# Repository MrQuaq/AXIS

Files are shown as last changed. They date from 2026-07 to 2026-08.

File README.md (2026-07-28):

# **AXIS — Balancing robot**

***AXIS is a dual wheeled self-balancing robot built around an ESP32 and custom PCB!***

### **Project overview**

AXIS is a dual wheeled balancing robot, using a PID algorithm to keep its balance. The main microcontroller of the robot will be the ESP32. This enables the use of an Xbox controller for controlling the robot. Certain buttons on the controller will be mapped to the pid value settings so they can be changed on the fly, which should make the tuning process a lot easier.

As an additional feature that will be tested after the robot is already stable, 2 encoders that are already mounted on the motors will be added. Their data will be used in a second PID algorithm to hopefully get the robot to stay in a single place a lot easier. This feature is still completely optional and can easily be turned on by a button on the Xbox controller.

### **Goals**

The goal of this project is to become more familiarized with electronics to get a good foundation for future projects. And to grasp the basics of PCB-design.

The goal for the robot itself is to make it balance without jittering too much and to make it drivable via a controller.

### **Key components**

- Custom PCB to mount breakout boards on  
- 3D-printed frame  
- Custom code featuring a PID algorithm and bluetooth connection

### **PCB design**

This PCB features lots of female header pins to mount existing breakout boards onto. This framework makes for more reliable connections and pcb-design experience.  
To design the board I used KiCAD, a free open-source EDA.

The first step in the design process was coming up with the requirements and features of the board.  
These include:

- Measuring the robots angle reliably  
- Driving the motors  
- Being able to connect a small lcd display for easier status updates and eventually PID tuning  
- Accept power from a 7,2V NiMH battery  
- Have connectors for encoders

After setting these requirements, a schematic was designed before moving on to the actual tracing. This also enabled me to become even more familiarized with the design and the components.

With the schematic made, the pcb tracing was fairly easy. I paid special attention to the spacing between the female pin headers so the modules would fit properly. A ground plane was also added on the bottom of the PCB to make wiring easier. To disturb this plane as little as possible, I tried to lay out the PCB in such a way that I have almost no traces on the back side.  
The final PCB features:

- Headers for ESP32  
- Headers for IMU module (ICM20948)  
- Headers for motor driver (tb6612fng)  
- Headers for lcd display  
- Screw terminals for motors and encoders  
- Components to provide the right (and stable) voltages to all components  
- Protection components

### **3D-CAD**

For the CAD I used a program I’m fairly familiar with; Fusion 360.  
The frame is divided into 3 key parts:

- Motor mount  
- Bottom compartment  
- Top compartment

The motor mount is made so that the motor has no room to shake. This results in a weird internal shape because of the irregular shape of the motor with right angle gearbox. Additionally the motor is able to be secured with 4 screws via the motor mount cover. This cover also features some cooling slots (but I doubt I need them).

Further up, we have the bottom compartment of the head. This houses the custom PCB. Connections to the encoders and motors pass through the bottom to the motor mount.

Above, there is the top compartment of the head. Here is the battery, LCD screen and switch. Again, their connections will pass through the bottom to the compartment below.  
Finally a lid, secured with magnets for easy access, covers up the top.

### **Timeline**

What’s already been done:

- Full code (imu, controller, PID’s and motor)  
- PCB design in KiCad  
- IMU testing  
- Motor testing  
- PID testing (imu and motor)  
- 3D-CAD

What still needs to be done:

- 3D printing the frame  
- Ordering the PCB  
- Final assembly  
- PID tuning

### **Gallery**

##### 3D-CAD

| | |
| :---: | :---: |
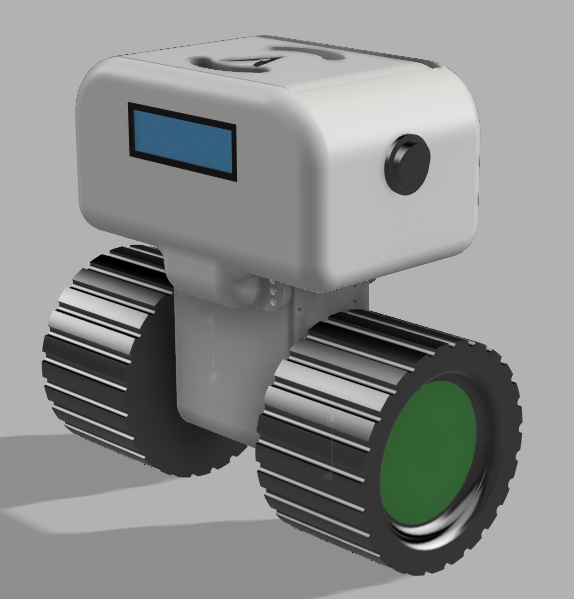
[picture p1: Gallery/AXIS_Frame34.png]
AXIS Frame 34
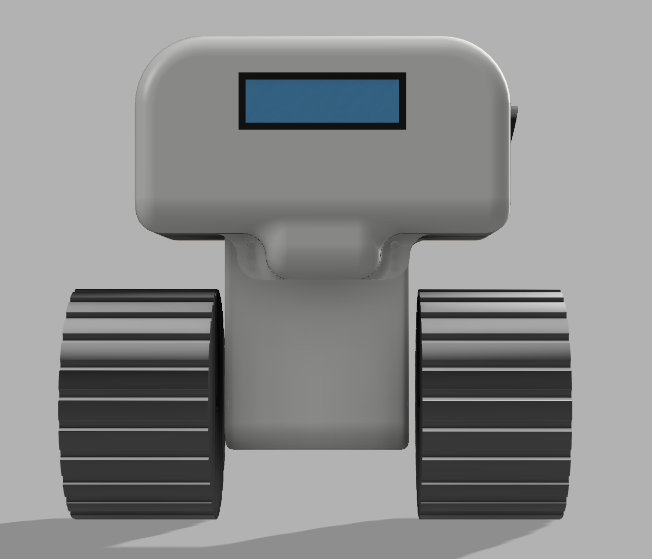
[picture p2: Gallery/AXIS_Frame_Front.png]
AXIS Frame Front
|  |  |
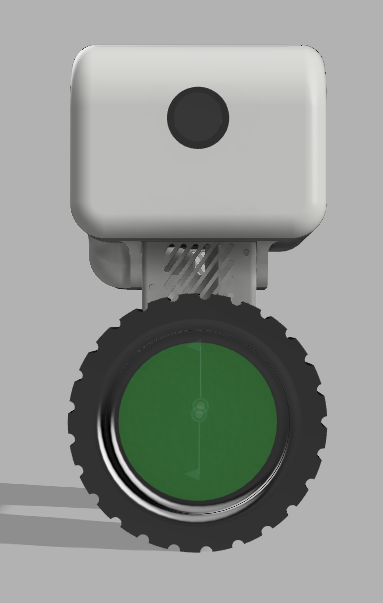
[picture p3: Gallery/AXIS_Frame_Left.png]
AXIS Frame Left
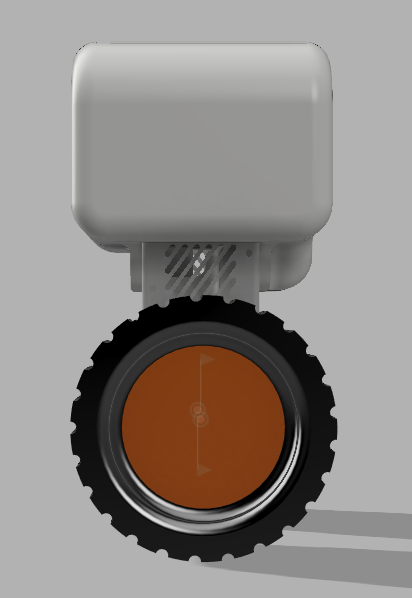
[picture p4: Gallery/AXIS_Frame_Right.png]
AXIS Frame Right
|  |  |
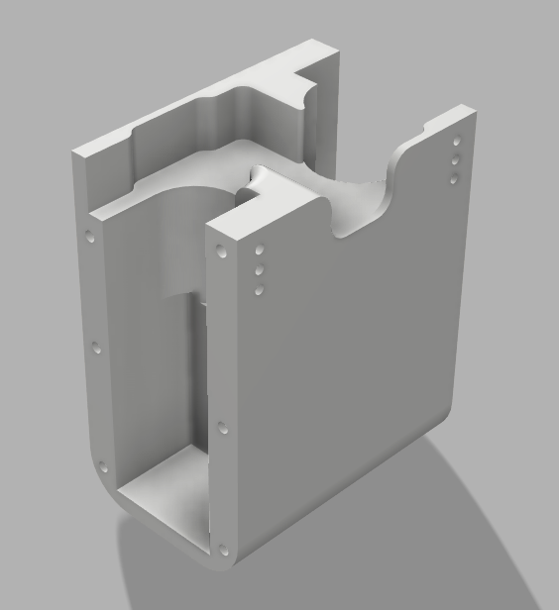
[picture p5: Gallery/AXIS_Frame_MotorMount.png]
AXIS Frame Motor Mount
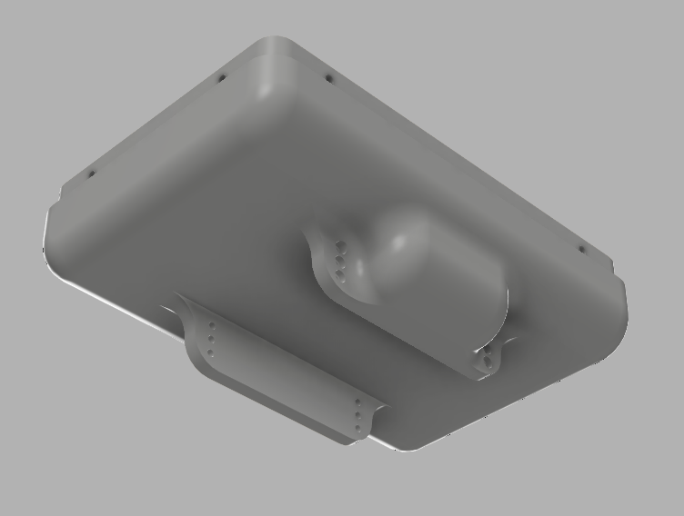
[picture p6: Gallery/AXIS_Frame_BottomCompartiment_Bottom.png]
AXIS Frame Bottom Compartiment Bottom
|  |  |
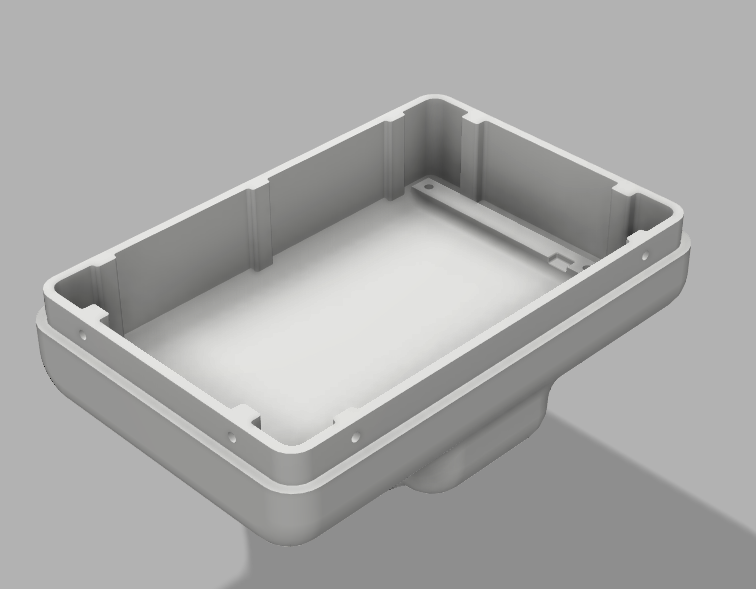
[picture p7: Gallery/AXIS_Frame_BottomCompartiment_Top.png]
AXIS Frame Bottom Compartiment Top
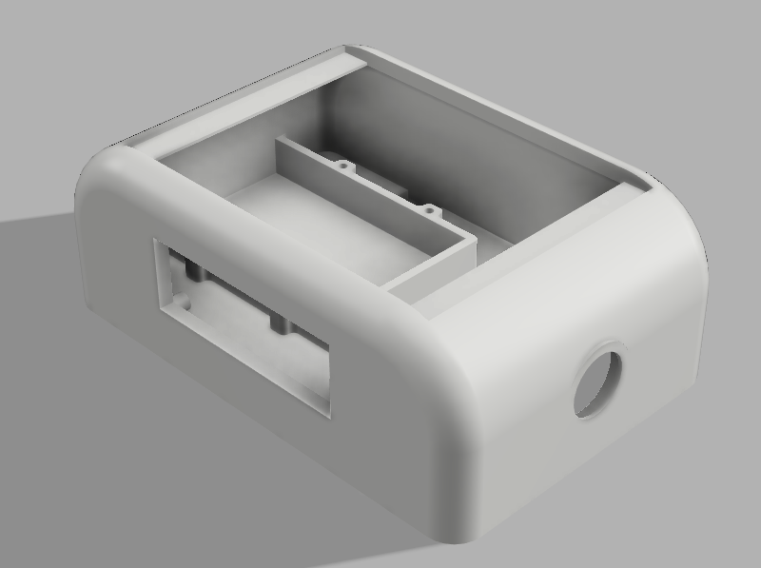
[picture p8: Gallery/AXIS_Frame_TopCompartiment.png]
AXIS Frame Top Compartiment
|  |  |

##### PCB-design

| | |
| :---: | :---: |
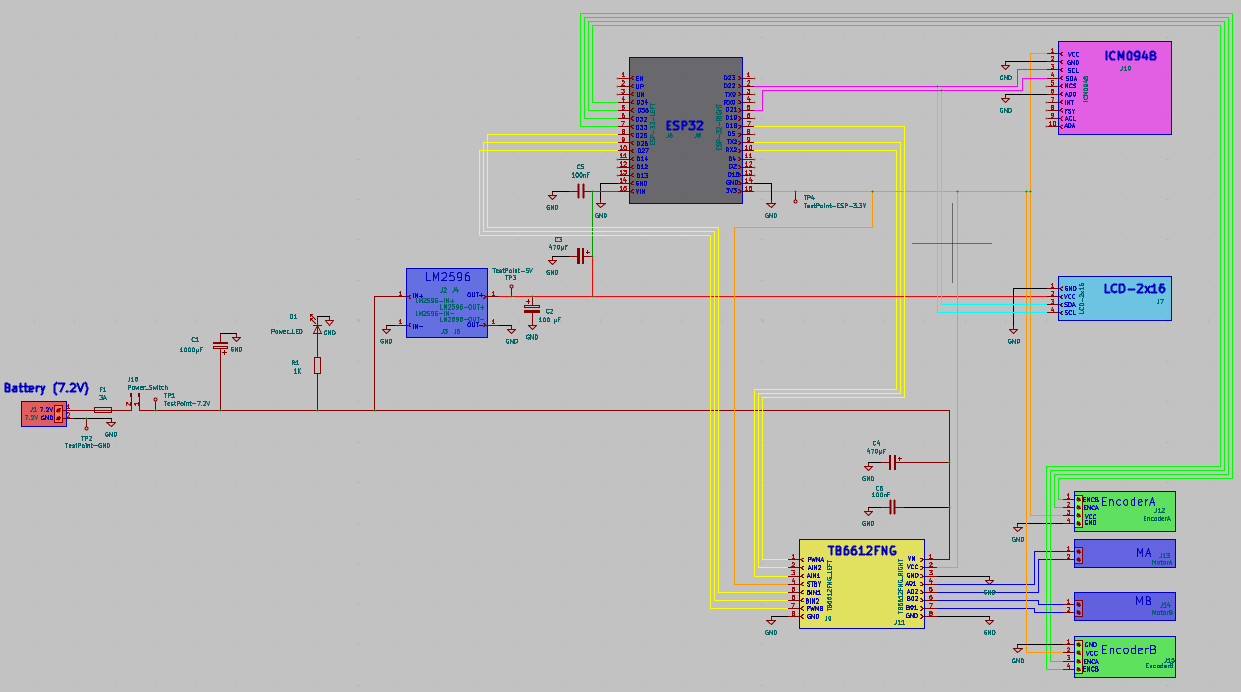
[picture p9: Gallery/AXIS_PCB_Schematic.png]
AXIS PCB Schematic
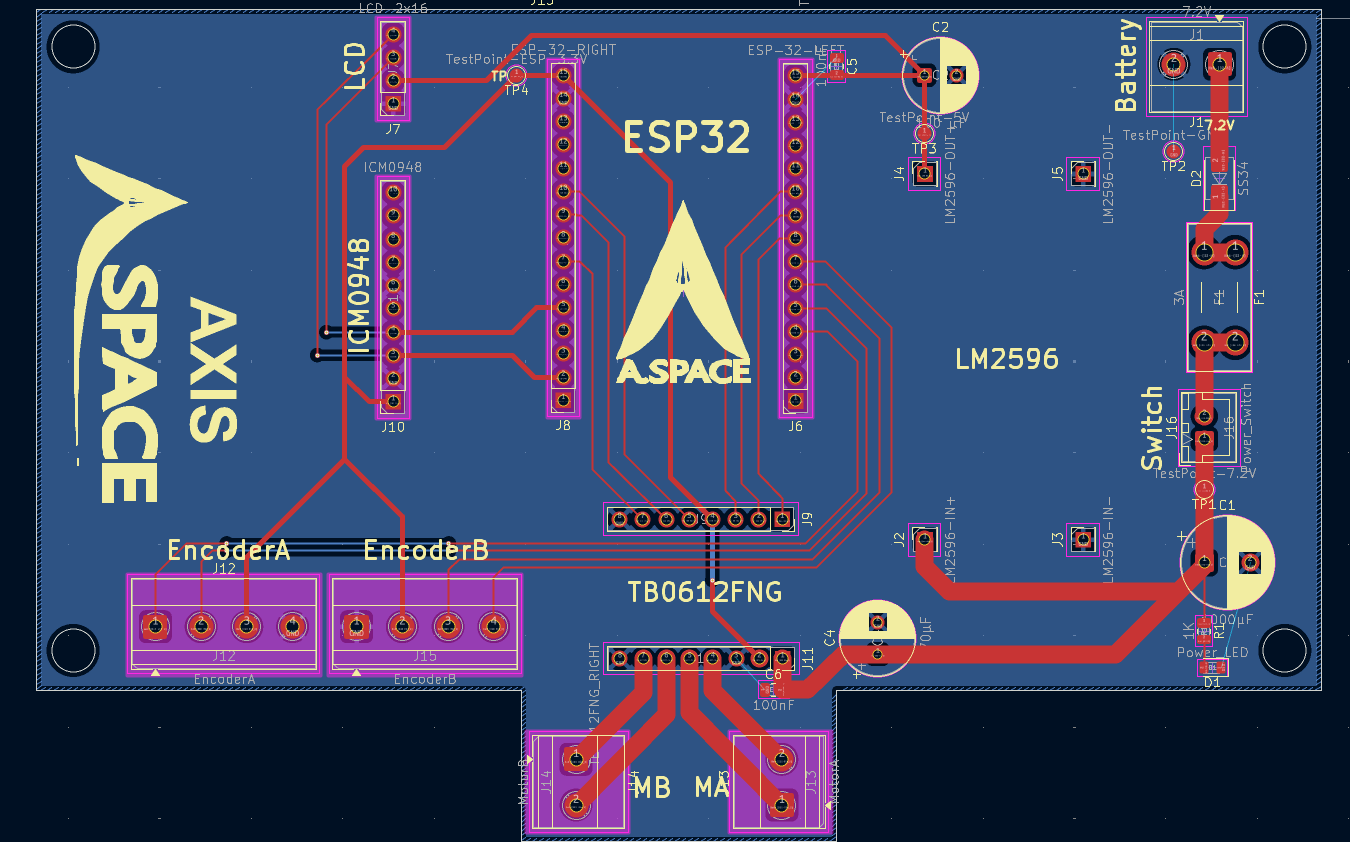
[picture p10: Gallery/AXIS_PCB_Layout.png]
AXIS PCB Layout
|  |  |
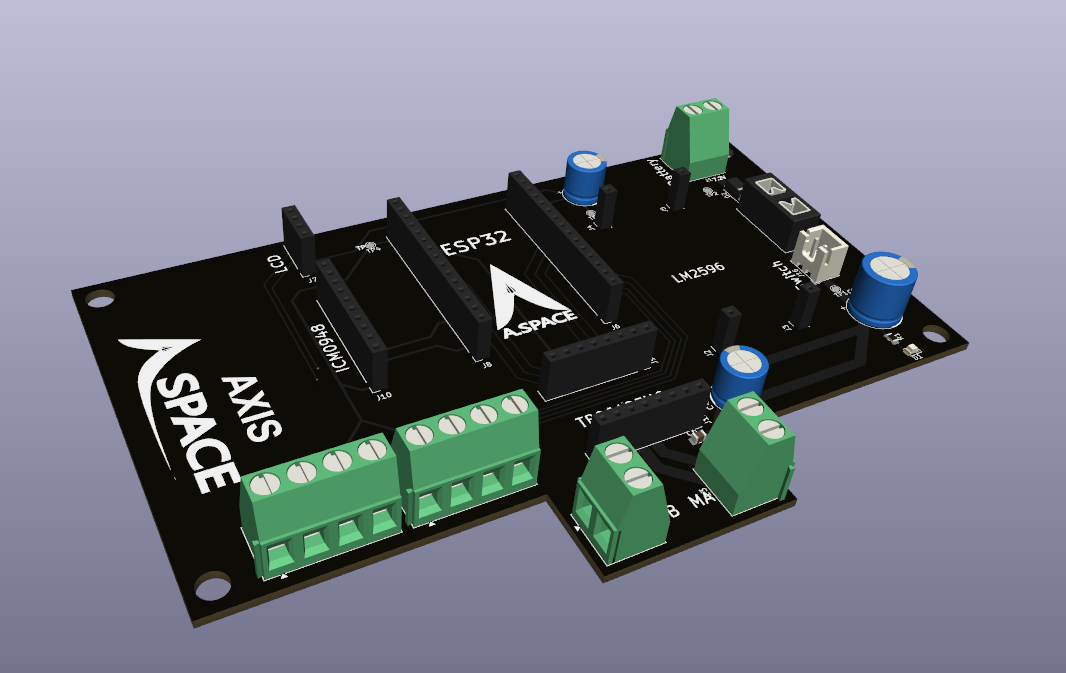
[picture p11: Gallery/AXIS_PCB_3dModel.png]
AXIS PCB 3dModel
|  | |

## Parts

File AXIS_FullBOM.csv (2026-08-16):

Part | Quantity | In possesion
ESP-32 module | 1 | TRUE
TB6612FNG module | 1 | TRUE
LM2596 module | 1 | TRUE
DC motor with encoder | 2 | TRUE
16 char LCD display | 1 | TRUE
7,2V Ni Mah battery | 1 | TRUE
switch | 1 | TRUE
Part | Quantity | In possesion
1kg PLA filament | 1 | TRUE
Wheel | 2 | TRUE
Index | Manufacturer Part Number | Manufacturer Name | Description | Attrition % | Requested Quantity 1 | Pack Quantity 1 | Pack Type 1 | Digi-Key Part Number 1 | Unit Price 1 | Extended Price 1 | Minimum Order Quantity 1 | Requested Part Number | Reference Designator | Original Part numbers | Unit of Measure | Product Notes
1 | SS34 | Shenzhen Slkormicro Semicon Co., Ltd. | DIODE SCHOTTKY 40V 3A DO214AC |  | 2 | 2 | Cut Tape (CT) | 5399-SS34CT-ND | 0,13000 | €0.26 | 1 | 5399-SS34CT-ND |  | 5399-SS34CT-ND | Each
2 | 3568 | Keystone Electronics | FUSE HOLDER BLADE 500V 30A PCB |  | 2 | 2 | Bulk | 36-3568-ND | 1,18000 | €2.36 | 1 | 36-3568-ND |  | 36-3568-ND | Each
3 | 1729128 | Phoenix Contact | TERM BLK 2P SIDE ENT 5.08MM PCB |  | 6 | 6 | Bulk | 277-1247-ND | 0,83000 | €4.98 | 1 | 277-1247-ND |  | 277-1247-ND | Each
4 | 1729144 | Phoenix Contact | TERM BLK 4P SIDE ENT 5.08MM PCB |  | 4 | 4 | Bulk | 277-1249-ND | 1,70000 | €6.80 | 1 | 277-1249-ND |  | 277-1249-ND | Each
5 | SSW-101-02-G-S | Samtec Inc. | CONN RCPT .100" 1POS SNGL GOLD |  | 8 | 8 | Bulk | 612-SSW-101-02-G-S-ND | 0,66000 | €5.28 | 1 | 612-SSW-101-02-G-S-ND |  | 612-SSW-101-02-G-S-ND | Each
6 | SSW-115-02-G-S | Samtec Inc. | CONN RCPT .100" 15POS SNGL GOLD |  | 4 | 4 | Bulk | 612-SSW-115-02-G-S-ND | 2,83000 | €11.32 | 1 | 612-SSW-115-02-G-S-ND |  | 612-SSW-115-02-G-S-ND | Each
7 | SSW-104-02-G-S | Samtec Inc. | CONN RCPT .100" 4POS SNGL GOLD |  | 2 | 2 | Bulk | 612-SSW-104-02-G-S-ND | 1,22000 | €2.44 | 1 | 612-SSW-104-02-G-S-ND |  | 612-SSW-104-02-G-S-ND | Each
8 | SSW-110-02-G-S | Samtec Inc. | CONN RCPT .100" 10POS SNGL GOLD |  | 2 | 2 | Bulk | 612-SSW-110-02-G-S-ND | 1,89000 | €3.78 | 1 | 612-SSW-110-02-G-S-ND |  | 612-SSW-110-02-G-S-ND | Each
9 | SSW-108-02-G-S | Samtec Inc. | CONN RCPT .100" 8POS SNGL GOLD |  | 4 | 4 | Bulk | 612-SSW-108-02-G-S-ND | 1,51000 | €6.04 | 1 | 612-SSW-108-02-G-S-ND |  | 612-SSW-108-02-G-S-ND | Each
10 | B2B-XH-A | JST Sales America Inc. | CONN HEADER VERT 2POS 2.5MM |  | 2 | 2 | Bulk | 455-B2B-XH-A-ND | 0,09000 | €0.18 | 1 | 455-B2B-XH-A-ND |  | 455-B2B-XH-A-ND | Each
11 | RC0805FR-131KL | YAGEO | RES 1K OHM 1% 1/8W 0805 |  | 2 | 2 | Cut Tape (CT) | 13-RC0805FR-131KLCT-ND | 0,09000 | €0.18 | 1 | 13-RC0805FR-131KLCT-ND |  | 13-RC0805FR-131KLCT-ND | Each
12 | 16SEPF1000M | Panasonic Industry | CAP ALUM POLY 1000UF 20% 16V TH |  | 2 | 2 | Bulk | P16300-ND | 2,21000 | €4.42 | 1 | P16300-ND |  | P16300-ND | Each
13 | 16SEPG470M | Panasonic Industry | CAP ALUM POLY 470UF 20% 16V TH |  | 2 | 2 | Bulk | P122605-ND | 1,52000 | €3.04 | 1 | P122605-ND |  | P122605-ND | Each
14 | C0805J104K3RACTU | KEMET | .100UF 25.0V |  | 4 | 4 | Cut Tape (CT) | 399-C0805J104K3RACTUCT-ND | 0,67000 | €2.68 | 1 | 399-C0805J104K3RACTUCT-ND |  | 399-C0805J104K3RACTUCT-ND | Each
15 | LG R971-KN-1-0-20-R18 | ams OSRAM AG | LED GREEN DIFFUSED 0805 SMD |  | 2 | 2 | Cut Tape (CT) | 475-LGR971-KN-1CT-ND | 0,15000 | €0.30 | 1 | 475-LGR971-KN-1CT-ND |  | 475-LGR971-KN-1CT-ND | Each
16 | 35RX30100M8X11.5 | Rubycon | CAP ALUM 100UF 20% 35V RADIAL TH |  | 2 | 2 | Bulk | 1189-1895-ND | 0,47000 | €0.94 | 1 | 1189-1895-ND |  | 1189-1895-ND | Each
 | PCB | PCB Parts | Total needed
 | €35.52 | €55,00 | €90,52

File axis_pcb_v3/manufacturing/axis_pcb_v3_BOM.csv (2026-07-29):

Comment | Designator | Footprint | Quantity
Power_LED | D1 | LED_0805_2012Metric | 1
LM2596-OUT+ | J4 | PinSocket_1x01_P2.54mm_Vertical | 1
100nF | C5,C6 | C_0805_2012Metric | 2
TestPoint-GND | TP2 | TestPoint_Pad_D1.5mm | 1
ESP-32-LEFT | J6 | PinSocket_1x15_P2.54mm_Vertical | 1
MotorB | J14 | TerminalBlock_Phoenix_MKDS-1,5-2_1x02_P5.00mm_Horizontal | 1
TestPoint-ESP-3.3V | TP4 | TestPoint_Pad_D1.5mm | 1
MotorA | J13 | TerminalBlock_Phoenix_MKDS-1,5-2_1x02_P5.00mm_Horizontal | 1
EncoderB | J15 | TerminalBlock_Phoenix_MKDS-1,5-4_1x04_P5.00mm_Horizontal | 1
TestPoint-7.2V | TP1 | TestPoint_Pad_D1.5mm | 1
1000µF | C1 | CP_Radial_D10.0mm_P5.00mm | 1
7.2V | J1 | TerminalBlock_Phoenix_MKDS-1,5-2_1x02_P5.00mm_Horizontal | 1
SS34 | D2 | D_SMA | 1
ICM0948 | J10 | PinSocket_1x10_P2.54mm_Vertical | 1
470µF | C4 | CP_Radial_D8.0mm_P3.50mm | 1
TB6612FNG_LEFT | J9 | PinSocket_1x08_P2.54mm_Vertical | 1
LM2596-IN- | J3 | PinSocket_1x01_P2.54mm_Vertical | 1
ESP-32-RIGHT | J8 | PinSocket_1x15_P2.54mm_Vertical | 1
TB6612FNG_RIGHT | J11 | PinSocket_1x08_P2.54mm_Vertical | 1
LCD-2x16 | J7 | PinSocket_1x04_P2.54mm_Vertical | 1
LM2596-OUT- | J5 | PinSocket_1x01_P2.54mm_Vertical | 1
Power_Switch | J16 | JST_XH_B2B-XH-A_1x02_P2.50mm_Vertical | 1
3A | F1 | Fuseholder_Blade_Mini_Keystone_3568 | 1
LM2596-IN+ | J2 | PinSocket_1x01_P2.54mm_Vertical | 1
100 µF | C2 | CP_Radial_D8.0mm_P3.50mm | 1
TestPoint-5V | TP3 | TestPoint_Pad_D1.5mm | 1
1K | R1 | R_0805_2012Metric | 1
EncoderA | J12 | TerminalBlock_Phoenix_MKDS-1,5-4_1x04_P5.00mm_Horizontal | 1

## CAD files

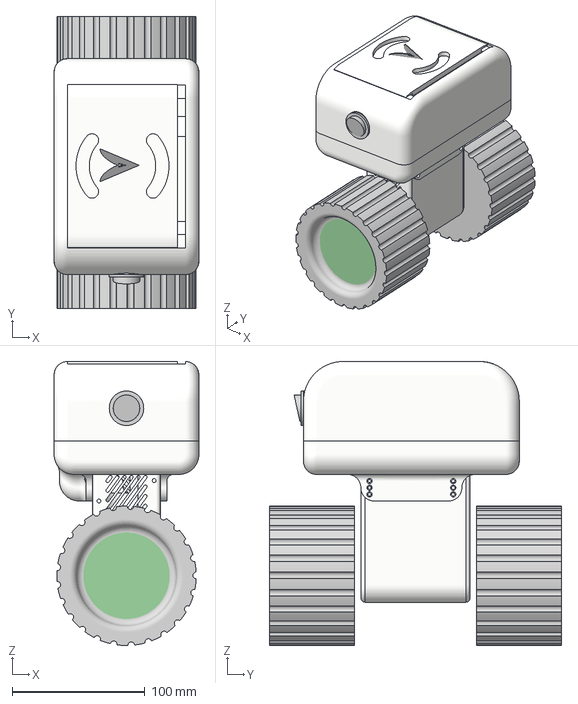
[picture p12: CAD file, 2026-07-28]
AXIS_Frame/AXIS_Frame_Assembly.3mf
109.0 x 220.0 x 213.7 mm

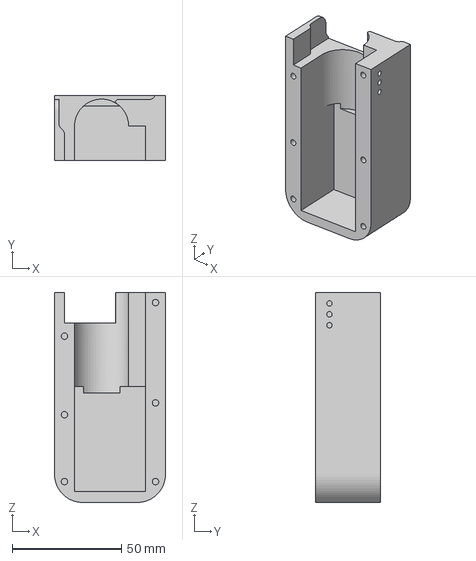
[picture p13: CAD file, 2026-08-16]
AXIS_Frame/MotorMountTest.3mf
50.9 x 30.0 x 96.2 mm

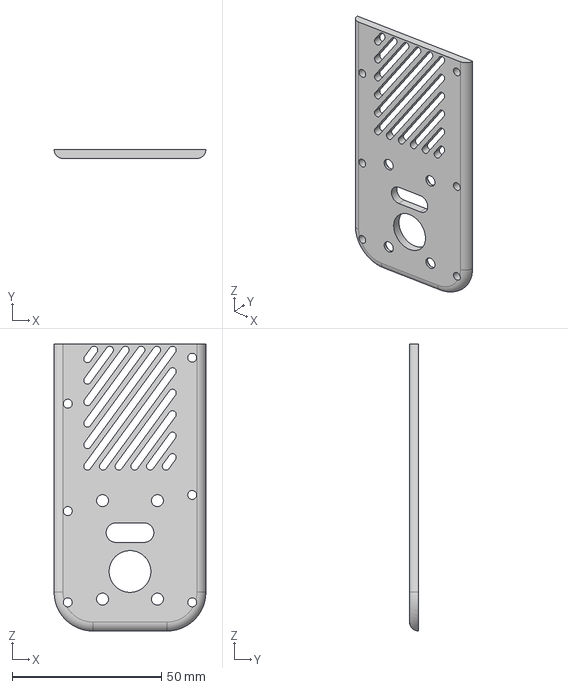
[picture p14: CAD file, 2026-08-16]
AXIS_Frame/MotorCover.step
50.9 x 3.00 x 96.2 mm

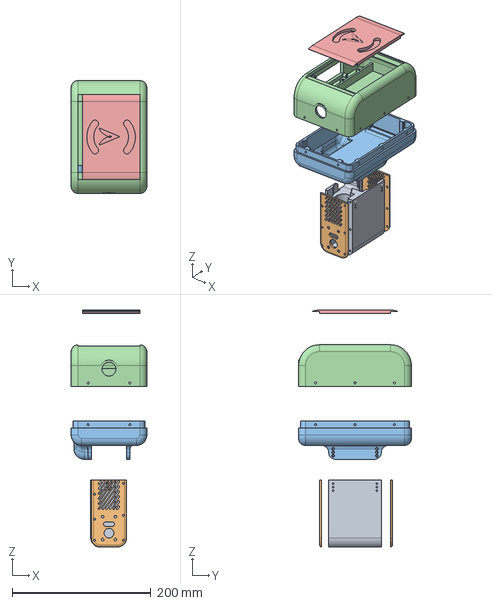
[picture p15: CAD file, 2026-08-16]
AXIS_Frame/AXIS_Frame_DesignFile.step
109.0 x 162.5 x 341.2 mm

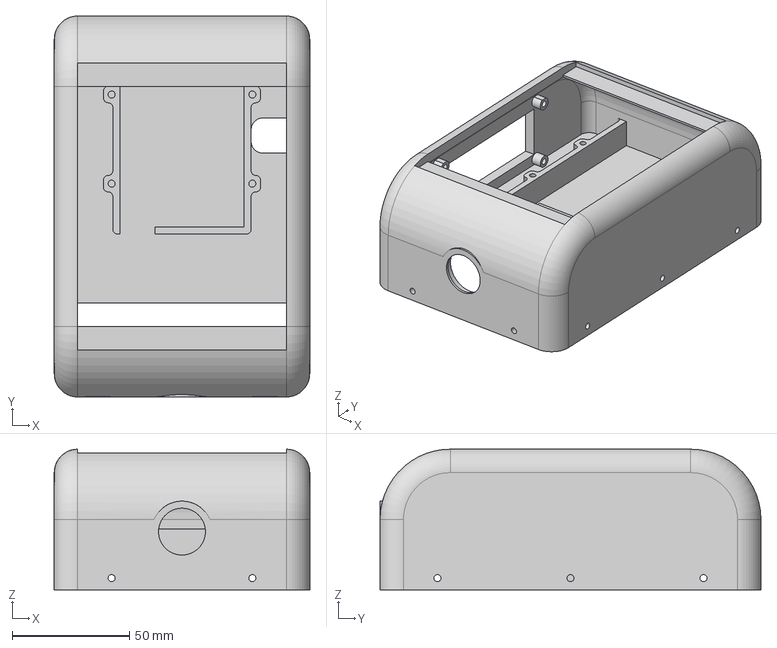
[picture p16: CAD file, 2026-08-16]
AXIS_Frame/TopCompartiment.step
109.0 x 162.5 x 60.0 mm

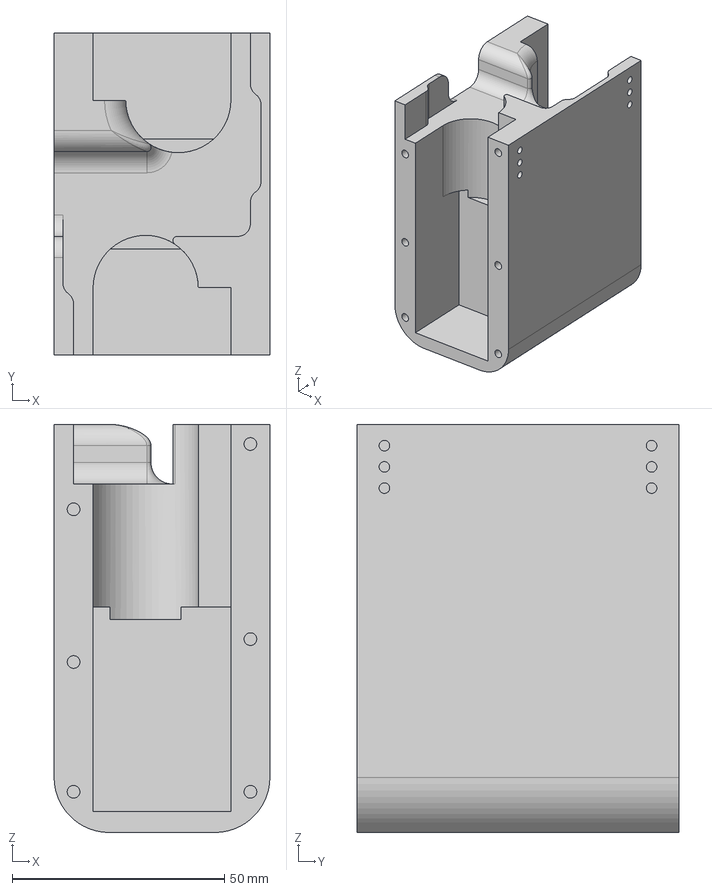
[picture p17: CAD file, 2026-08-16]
AXIS_Frame/MotorMount.step
50.9 x 76.0 x 96.2 mm

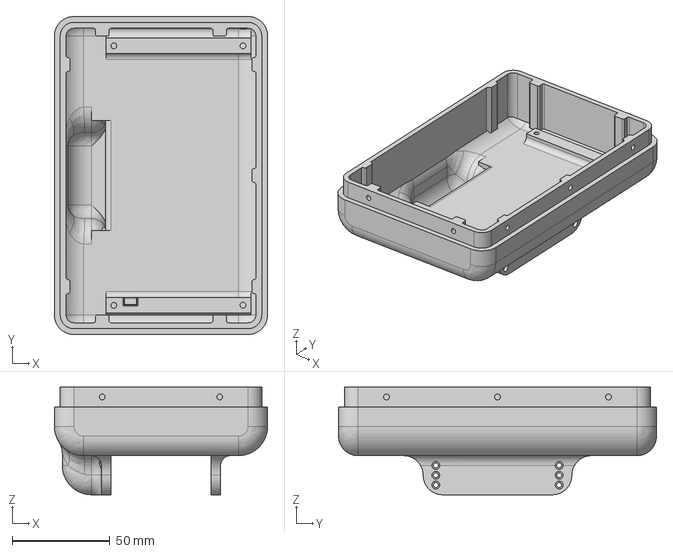
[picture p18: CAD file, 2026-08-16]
AXIS_Frame/BottomCompartiment.step
109.0 x 162.5 x 55.0 mm

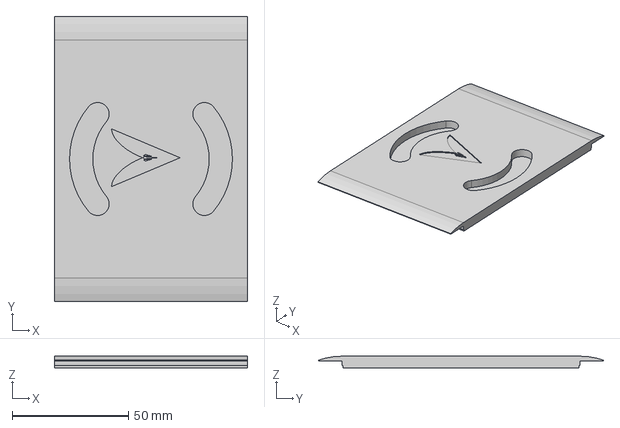
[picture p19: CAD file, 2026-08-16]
AXIS_Frame/TopCover.step
83.0 x 122.5 x 5.00 mm

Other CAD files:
AXIS_Frame/MotorMountCover.3mf
AXIS_Frame/AXIS_MotorMountCover_Test.stl
AXIS_Frame/AXIS_MotorMount_Test.stl
AXIS_Frame/BottomCompartiment.3mf
AXIS_Frame/MotorMount.3mf
AXIS_Frame/TopCompartiment.3mf
AXIS_Frame/TopCover.3mf

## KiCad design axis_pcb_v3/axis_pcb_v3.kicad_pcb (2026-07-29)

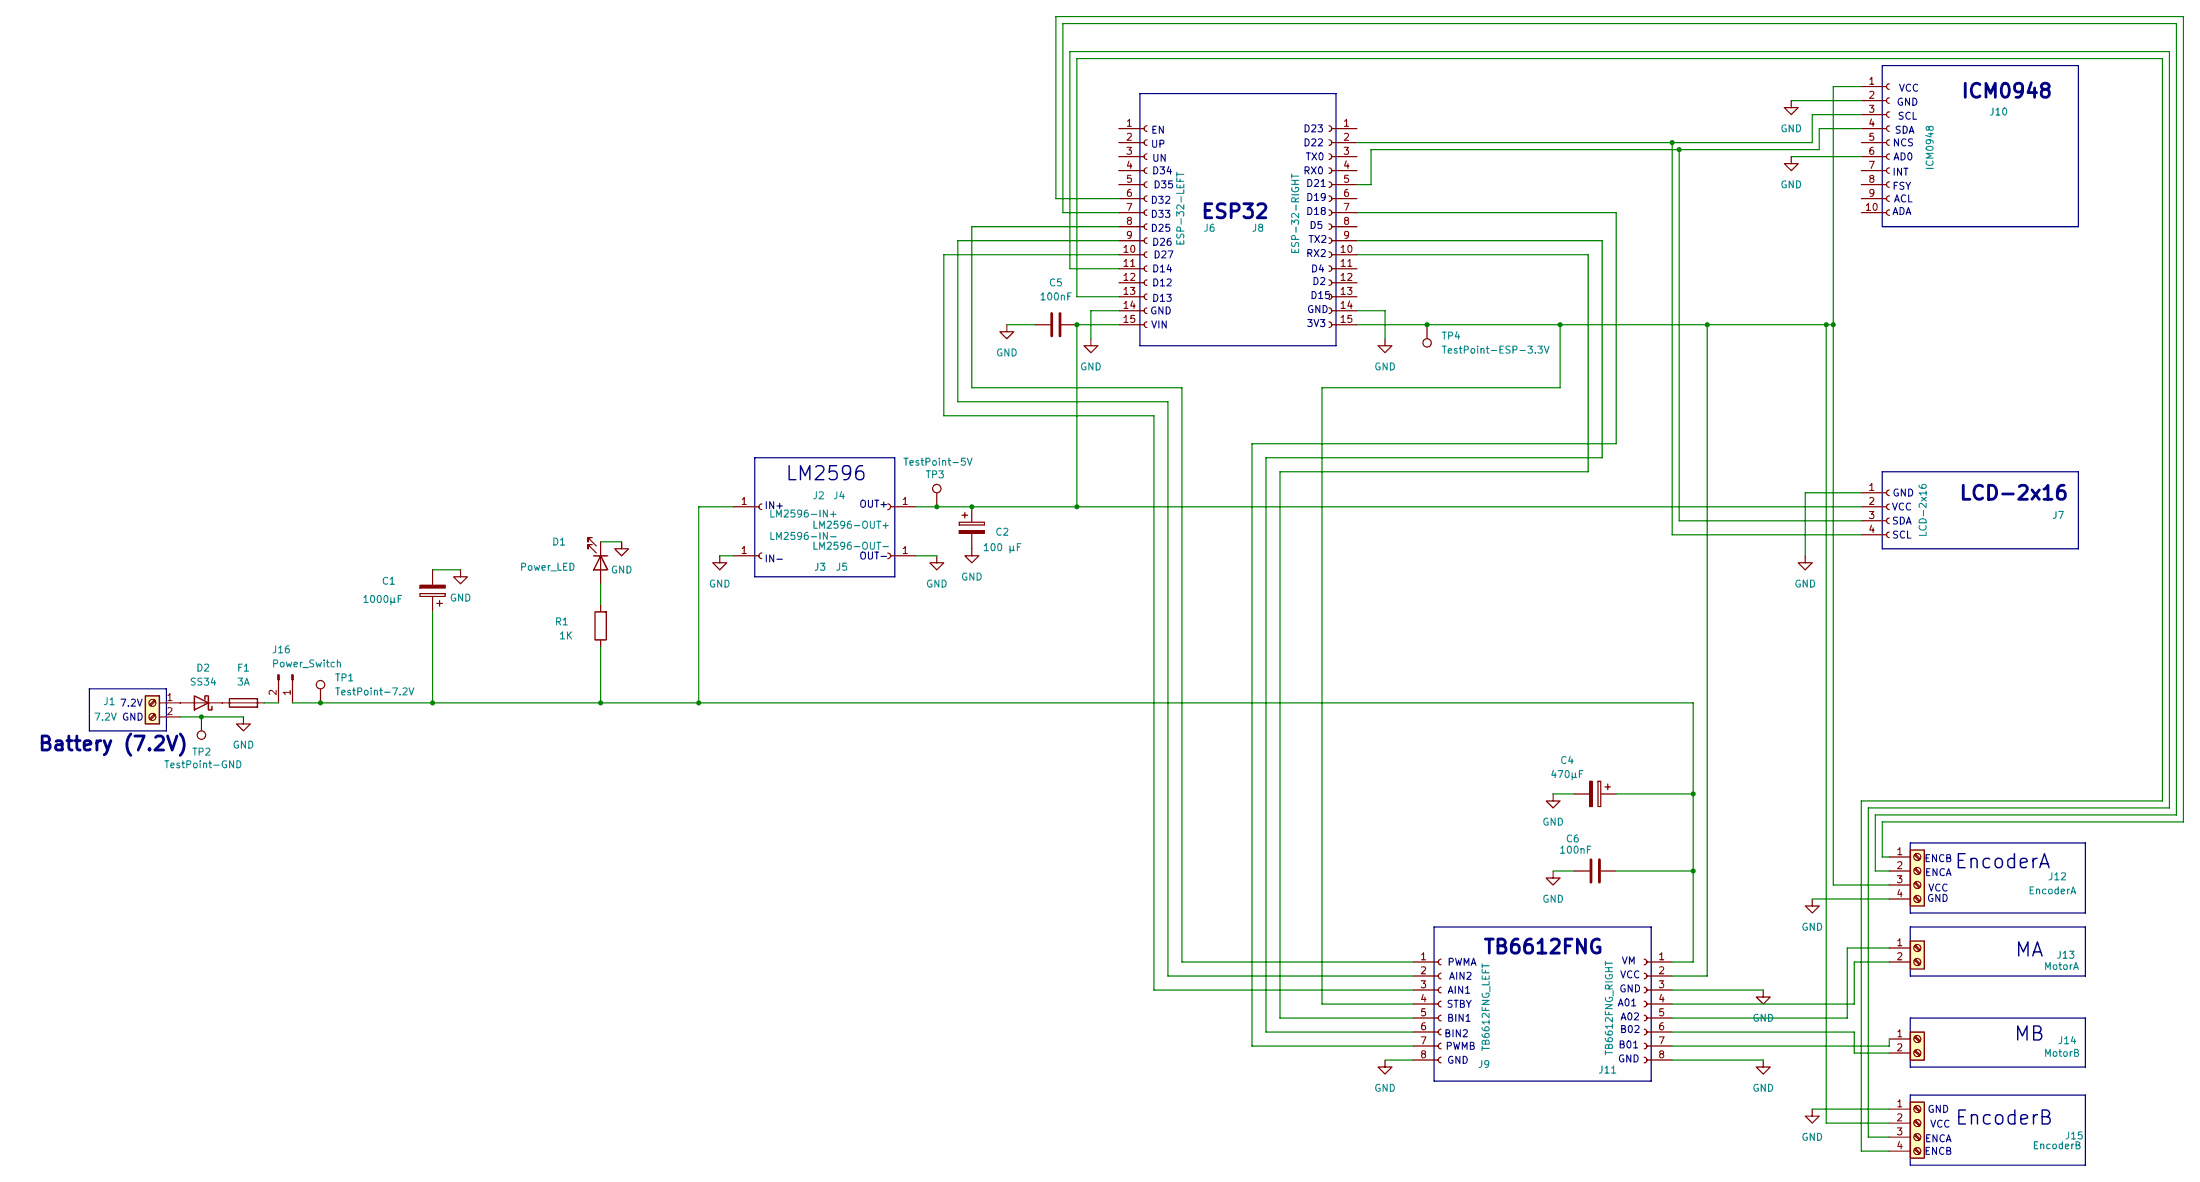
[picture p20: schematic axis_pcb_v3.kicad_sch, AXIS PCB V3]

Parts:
C1: 1000µF; CP_Radial_D10.0mm_P5.00mm
C2: 100 µF; CP_Radial_D8.0mm_P3.50mm
C4: 470µF; CP_Radial_D8.0mm_P3.50mm
C5, C6: 100nF; C_0805_2012Metric
D1: Power_LED; LED_0805_2012Metric
D2: SS34; D_SMA
F1: 3A; Fuseholder_Blade_Mini_Keystone_3568
J1: 7.2V; TerminalBlock_Phoenix_MKDS-1,5-2_1x02_P5.00mm_Horizontal
J2: LM2596-IN+; PinSocket_1x01_P2.54mm_Vertical
J3: LM2596-IN-; PinSocket_1x01_P2.54mm_Vertical
J4: LM2596-OUT+; PinSocket_1x01_P2.54mm_Vertical
J5: LM2596-OUT-; PinSocket_1x01_P2.54mm_Vertical
J6: ESP-32-LEFT; PinSocket_1x15_P2.54mm_Vertical
J7: LCD-2x16; PinSocket_1x04_P2.54mm_Vertical
J8: ESP-32-RIGHT; PinSocket_1x15_P2.54mm_Vertical
J9: TB6612FNG_LEFT; PinSocket_1x08_P2.54mm_Vertical
J10: ICM0948; PinSocket_1x10_P2.54mm_Vertical
J11: TB6612FNG_RIGHT; PinSocket_1x08_P2.54mm_Vertical
J12: EncoderA; TerminalBlock_Phoenix_MKDS-1,5-4_1x04_P5.00mm_Horizontal
J13: MotorA; TerminalBlock_Phoenix_MKDS-1,5-2_1x02_P5.00mm_Horizontal
J14: MotorB; TerminalBlock_Phoenix_MKDS-1,5-2_1x02_P5.00mm_Horizontal
J15: EncoderB; TerminalBlock_Phoenix_MKDS-1,5-4_1x04_P5.00mm_Horizontal
J16: Power_Switch; JST_XH_B2B-XH-A_1x02_P2.50mm_Vertical
R1: 1K; R_0805_2012Metric
TP1: TestPoint-7.2V; TestPoint_Pad_D1.5mm
TP2: TestPoint-GND; TestPoint_Pad_D1.5mm
TP3: TestPoint-5V; TestPoint_Pad_D1.5mm
TP4: TestPoint-ESP-3.3V; TestPoint_Pad_D1.5mm

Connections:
GND: C1.2, C2.2, C4.2, C5.1, C6.1, D1.1 (K), J1.2, J3.1, J5.1, J6.14, J7.1, J8.14, J9.8, J10.2, J10.6, J11.3, J11.8, J12.4, J15.1, TP2.1
unnamed: D1.2 (A), R1.2
unnamed: D2.2 (A), J1.1
unnamed: D2.1 (K), F1.1
unnamed: C2.1, C5.2, J4.1, J6.15, J7.2, TP3.1
unnamed: J6.8, J9.1
unnamed: J6.9, J9.2
unnamed: J6.10, J9.3
unnamed: J8.7, J9.7
unnamed: J8.9, J9.6
unnamed: J8.10, J9.5
unnamed: J8.15, J9.4, J10.1, J11.2, J12.3, J15.2, TP4.1
unnamed: J7.4, J8.2, J10.3
unnamed: J7.3, J8.5, J10.4
unnamed: C1.1, C4.1, C6.2, J2.1, J11.1, J16.1, R1.1, TP1.1
unnamed: J11.4, J13.2
unnamed: J11.5, J13.1
unnamed: J11.6, J14.2
unnamed: J11.7, J14.1
unnamed: J6.6, J12.1
unnamed: J6.7, J12.2
unnamed: J6.11, J15.3
unnamed: J6.13, J15.4
unnamed: F1.2, J16.2

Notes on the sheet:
EncoderB
PWMA
3V3
D35
D25
D12
ENCA
BIN1
ACL
D26
LM2596
VCC
D34
D13
D21
INT
SCL
VIN
GND
SDA
AIN1
RX0
OUT+
D23
TX0
A02
7.2V
TB6612FNG
B01
D19
TX2
AD0
STBY
OUT-
D22
NCS
EncoderA
ENCB
RX2
ADA

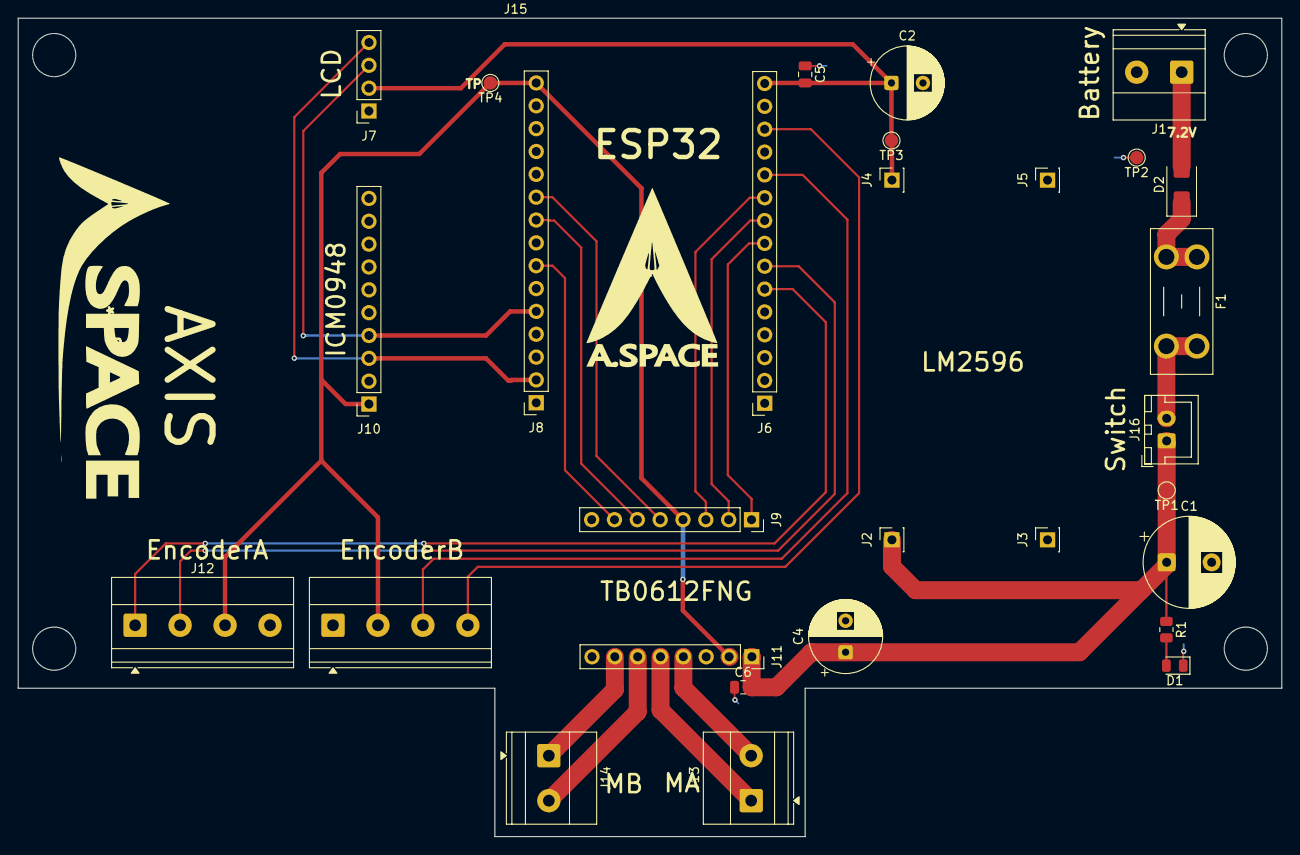
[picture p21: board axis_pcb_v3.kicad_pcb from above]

Board: 2 copper layers, 140.5 x 91.0 mm, 29 parts (0 on the bottom side), 24 nets.

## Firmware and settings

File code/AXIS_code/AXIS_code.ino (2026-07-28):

#include "Globals.h"

double dt = 0.0;
unsigned long last_time;

extern float angle;

double FINALPID_OUTPUT;
double PID_OUTPUT;
double SPEEDPID_OUTPUT;

void setup() {
  setupmotor();
  setupIMU();
  setupcontroller();
  setupEncoders();

  Serial.begin(9600);
}

void loop() {
  //--------DELTA TIME CALCULATION-----------------
  unsigned long now = micros();
  dt = (now - last_time) / 1000000.0;
  last_time = now;

  //-----------FUNCTIONS-----------------
  updateIMU();
  int pwm = controller();
  motor(pwm, FINALPID_OUTPUT);  

  Serial.print(angle);
  Serial.print(",");
  Serial.println(pwm);
}

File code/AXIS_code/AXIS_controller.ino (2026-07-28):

#include "Globals.h"
#include <LiquidCrystal_I2C.h>

//--------GLOBAL VARIABLES------------
extern double dt;
extern unsigned long last_time;
extern float angle;

// Ensure these are defined globally in Globals.h or your main tab
extern double PID_OUTPUT;
extern double SPEEDPID_OUTPUT;

LiquidCrystal_I2C lcd(0x27, 16, 2);

// -------- ANGLE PID --------
double integral = 0.0;
double kp = 3.5;    // Start with a safe default instead of 0.0
double ki = 0.05;   
double kd = 0.1;    
double setpoint = 0.0;

// -------- SPEED PID --------
double speedIntegral = 0.0;
double lastSpeedError = 0.0;

double kp_speed = 0.05;   // Adjusted for cascade control scaling
double ki_speed = 0.001;
double kd_speed = 0.0;

// Track button press states to prevent rapid firing adjustments
unsigned long lastButtonTime = 0;

//--------------------------------------------------------------------------

// -------------------- CONTROLLER --------------------
ControllerPtr myControllers[BP32_MAX_GAMEPADS];

void onConnectedController(ControllerPtr ctl) {
  for (int i = 0; i < BP32_MAX_GAMEPADS; i++) {
    if (myControllers[i] == nullptr) {
      myControllers[i] = ctl;
      Serial.printf("Controller connected, index=%d\n", i);
      return;
    }
  }
  Serial.println("Controller connected, no empty slot");
}

void onDisconnectedController(ControllerPtr ctl) {
  for (int i = 0; i < BP32_MAX_GAMEPADS; i++) {
    if (myControllers[i] == ctl) {
      myControllers[i] = nullptr;
      Serial.printf("Controller disconnected, index=%d\n", i);
      return;
    }
  }
  Serial.println("Controller disconnected, not found");
}

void processGamepad(ControllerPtr ctl) {
  uint16_t buttons = ctl->buttons();

  // Rate limit button presses to once every 150ms so numbers change controllably
  if (millis() - lastButtonTime > 150) {
    // X button -> decrease kp
    if (ctl->x()) { kp -= 0.1; lastButtonTime = millis(); }
    // Y button -> increase kp
    if (ctl->y()) { kp += 0.1; lastButtonTime = millis(); }
    // Dpad UP -> increase ki
    if (buttons & 0x0001) { ki += 0.01; lastButtonTime = millis(); }
    // Dpad LEFT -> decrease ki
    if (buttons & 0x0008) { ki -= 0.01; lastButtonTime = millis(); }
    // Dpad RIGHT -> increase kd
    if (buttons & 0x0004) { kd += 0.01; lastButtonTime = millis(); }
    // Dpad DOWN -> decrease kd
    if (buttons & 0x0002) { kd -= 0.01; lastButtonTime = millis(); }
  }

  // Left joystick Y -> change setpoint
  if (ctl->axisY() <= -25) setpoint += 0.1; // Smaller increments for gentler trim tuning
  if (ctl->axisY() >= 25) setpoint -= 0.1;
}

void processControllers() {
  for (auto ctl : myControllers) {
    if (ctl && ctl->isConnected()) {
      if (ctl->isGamepad()) {
        processGamepad(ctl);
      }
    }
  }
}

// -------------------- PID FUNCTION --------------------
double PID(double error) {
  static double previous = 0.0;
  double proportional = error;
  
  integral += error * dt;
  integral = constrain(integral, -100, 100); // Anti-windup
  
  double derivative = 0.0;
  if (dt > 0.0) { // Protect against divide-by-zero crash
    derivative = (error - previous) / dt;
  }
  previous = error;
  
  return (kp * proportional) + (ki * integral) + (kd * derivative);
}

// -------------------- PID SPEED FUNCTION --------------------
double speedPID() {
  float leftSpeed = getLeftSpeed(dt);
  float rightSpeed = getRightSpeed(dt);
  float avgSpeed = (leftSpeed + rightSpeed) / 2.0;

  double speedError = 0.0 - avgSpeed;

  speedIntegral += speedError * dt;
  speedIntegral = constrain(speedIntegral, -50, 50);

  double speedDerivative = 0.0;
  if (dt > 0.0) {
    speedDerivative = (speedError - lastSpeedError) / dt;
  }

  lastSpeedError = speedError;
  return (kp_speed * speedError) + (ki_speed * speedIntegral) + (kd_speed * speedDerivative);
}

// -------------------- SETUP --------------------
void setupcontroller() {
  Serial.begin(115200);
  Wire.begin();

  // LCD
  lcd.init();
  lcd.backlight();

  // Removed the lines that reset kp, ki, kd to 0.0 instantly

  // Bluepad32
  BP32.setup(&onConnectedController, &onDisconnectedController);
  BP32.forgetBluetoothKeys();

  last_time = micros();
}

// -------------------- LOOP --------------------
int controller() {
  // Update controller inputs
  BP32.update();
  processControllers();

  double actual = angle;

  // 1. CASCADING APPROACH: Run the Speed PID first to find the angle offset adjustment
  SPEEDPID_OUTPUT = speedPID();
  
  // 2. Adjust target angle setpoint dynamically based on wheel velocity
  double adjustedSetpoint = setpoint + SPEEDPID_OUTPUT;

  // 3. Run Angle Control loop based on the new adjusted setpoint target
  double error = adjustedSetpoint - actual;
  PID_OUTPUT = PID(error);
  
  double FINALPID_OUTPUT = PID_OUTPUT;
  
  // Constrain to physical PWM limits
  FINALPID_OUTPUT = constrain(FINALPID_OUTPUT, -255, 255);
  int pwm = constrain(abs(FINALPID_OUTPUT), 0, 255);

  // LCD display PID values
  lcd.setCursor(0, 0);
  lcd.print("Kp:");
  lcd.print(kp, 1);
  lcd.print(" SP:");
  lcd.print(adjustedSetpoint, 1);
  
  lcd.setCursor(0, 1);
  lcd.print("P:");
  lcd.print(pwm);
  lcd.print(" Ang:");
  lcd.print(actual, 1);

  return(pwm);
}

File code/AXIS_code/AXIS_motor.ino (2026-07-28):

#define PWM_FREQ 20000
#define PWM_RES 8

#define CH1 0
#define CH2 1

#define PWMA 25
#define AIN1 27
#define AIN2 26

#define PWMB 18
#define BIN1 16
#define BIN2 17

#define STBY 23

void setupmotor() {

  pinMode(PWMA, OUTPUT);
  pinMode(PWMB, OUTPUT);

  pinMode(AIN1, OUTPUT);
  pinMode(AIN2, OUTPUT);
  pinMode(BIN1, OUTPUT);
  pinMode(BIN2, OUTPUT);

  ledcSetup(CH1, PWM_FREQ, PWM_RES);
  ledcAttachPin(PWMA, CH1);

  ledcSetup(CH2, PWM_FREQ, PWM_RES);
  ledcAttachPin(PWMB, CH2);
}

void motor(int pwm, double PID_OUTPUT){

  pwm = constrain(abs(pwm), 0, 255);

  if (FINALPID_OUTPUT < -20) {

    digitalWrite(AIN1, HIGH);
    digitalWrite(BIN1, HIGH);
    digitalWrite(AIN2, LOW);
    digitalWrite(BIN2, LOW);

    ledcWrite(CH1, pwm);
    ledcWrite(CH2, pwm);
  }

  else if (FINALPID_OUTPUT > 20) {

    digitalWrite(AIN1, LOW);
    digitalWrite(BIN1, LOW);
    digitalWrite(AIN2, HIGH);
    digitalWrite(BIN2, HIGH);

    ledcWrite(CH1, pwm);
    ledcWrite(CH2, pwm);
  }

  else {
    ledcWrite(CH1, 0);
    ledcWrite(CH2, 0);
  }
}

  
